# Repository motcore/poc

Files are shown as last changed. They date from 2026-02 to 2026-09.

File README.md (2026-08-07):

# Motcore

**Multi-Axis Actuator Tree — one motor, many axes**






> A novel approach to multi-axis actuation: one motor, multiple independently controlled axes through selective friction engagement.

<!-- TODO: demo video — once it's recorded and hosted, restore as the first item:
     [🎥 Demo Video](URL) | -->
[📖 Documentation](docs/) | [🧬 Design Evolution](docs/design-evolution.md) | [💬 Discussions](../../discussions) | [🐛 Issues](../../issues)

---

## 🚧 Project Status

**Current version: v0.1 - Proof of Concept**

This is an **early-stage open hardware project** developed in spare time. The current prototype uses LEGO Technic components to validate the core mechanical principle. It works, it demonstrates the concept, but it's not production-ready.

**What exists today:**
- ✅ Functional proof of concept
- ✅ Arduino-based control system
- ✅ Validated friction-based power transmission
- ✅ Independent control of 4 output axes

**What's being developed:**
- 🔄 v5 vertical cone clutch — geometry settled, CAD pending
- 🔄 3D-printable components (FreeCAD parametric models)
- 🔄 Comprehensive documentation
- 🔄 BOM with standard components

The mechanism has been through **five generations**. Four are superseded and
should not be re-proposed — see [Design Evolution](docs/design-evolution.md) for
what each one was and what killed it.

**Timeline:** When it's ready. No pressure, no deadlines. Life happens. 🙂

---

## 💡 The Problem

Traditional multi-axis systems face a fundamental trade-off:

| Approach | Cost | Complexity | Independent Control |
|---|---|---|---|
| **One motor per axis** | High | Low | ✅ Yes |
| **Mechanical coupling** | Medium | High | ❌ No (coupled motion) |
| **Motcore** | **Low** | **Medium** | **✅ Yes** |

**Motcore fills the gap:** affordable multi-axis control without sacrificing independence.

---

## 🎯 The Motcore Solution

### Core Innovation

A single continuously rotating motor drives multiple output axes through
**vertical conical friction clutches**. Each axis has its own clutch module on a
carriage that translates vertically; engaging a clutch connects that axis to the
motor cone. Each output feeds the **next hub of the tree**, so every level is a
reduction — torque is regenerated at each stage, and speed is the resource there
is plenty of.

```
        side view (one axis, Y-Z cross-section)

           motor axis (Z)
                │
                │        ┌───┐  ← output cone on carriage
                │       ╱     ╲       (translates vertically ↕)
                │      │  ○ ○  │ ── output shaft (fixed)
              ╱ │ ╲     ╲     ╱       + internal corona
             ╱  │  ╲     └───┘
            ╱ ○ │ ○ ╲   ← O-rings interleaved, flank to flank
           ╱────┴────╲
             motor cone
```

**Key principle:** selective friction engagement as a power transmission method —
with **free rotation obtained geometrically**, not by loosening a clutch.

### Features

✅ **Single inexpensive motor** — 28BYJ-48 stepper (€3)  
✅ **Independent axis control** — 4+ axes, each controllable separately  
✅ **Real free rotation** — a disengaged axis carries *nothing*, so an arm can fall under its own weight  
✅ **Reduction at every level** — 1.4× torque per stage, not 1:1  
✅ **Per-axis torque limiter** — slip threshold set in software by carriage position  
✅ **Scalable** — add more axes without changing the central motor  
✅ **Low cost** — complete system ~€50 in components  
✅ **Educational platform** — demonstrates mechanical principles elegantly  

---

## 🧠 Design Philosophy

Motcore is inspired by principles of elegant mechanical design:

**Passive Dynamics** (McGeer)  
Like passive walkers that minimize active control, Motcore leverages fundamental physics - friction as a natural power transmission medium.

**Underactuation** (MIT Underactuated Robotics)  
One motor powers multiple independent degrees of freedom through selective engagement. Fewer actuators, smarter design.

**Mechanical Intelligence** (Jansen's Strandbeests)  
The mechanism's geometry and material properties do the "thinking", reducing software complexity.

**Let the parts you already have do the work**  
The engagement stroke needs compliance to preload the friction surfaces. Rather
than add a spring, a slot or a flexure, v5 absorbs that travel in the **root
clearance of the gear it already needed**. No extra part, nothing to tune.

### Why This Matters

Traditional multi-axis systems fight complexity with more complexity (more motors, more controllers, more synchronization). Motcore embraces the opposite: **simplicity through smart exploitation of physical phenomena**.

This isn't just about cost - it's about design elegance.

---

## 🔧 Current Prototype: Arduino Cube

<!-- TODO: photo of the v0.1 LEGO prototype — save as docs/images/prototype-v01.jpg and restore:
     ![Motcore v0.1 Prototype](docs/images/prototype-v01.jpg) -->
*v0.1 proof of concept using LEGO Technic components*

### Technical Specifications

| Component | Specification |
|---|---|
| **Central Motor** | 28BYJ-48 stepper (5V, ~3.5Ω coil resistance) |
| **Motor Driver** | ULN2003 Darlington array |
| **Output Axes** | 4 perpendicular axes (5mm diameter) |
| **Engagement** | 4x SG90 servo motors with friction wheels |
| **Controller** | Arduino Uno (master) |
| **Driver Board** | Arduino Uno (receiver) |
| **Interface** | MCUFRIEND 2.4" TFT touchscreen (240x320) |
| **Communication** | Serial (9600 baud) |
| **Power** | 5V USB |

### How It Works (v0.1 prototype)

1. **Central motor rotates continuously** at constant speed
2. **Servos position friction wheels** to engage/disengage with output axes
3. **Output axes move laterally** to contact different sides of the central shaft
4. **Direction control** through selective engagement (clockwise/counterclockwise)
5. **Independent operation** - each axis controlled separately via touchscreen

*This describes the LEGO proof of concept, which validated the core principle.
The engagement mechanism has been redesigned four times since — see
[Design Evolution](docs/design-evolution.md).*

---

## 🎓 Applications

### Immediate Use Cases
- **Educational robotics** - teach mechanical power transmission
- **Low-cost automation** - simple pick-and-place systems
- **Rapid prototyping** - test multi-DOF concepts quickly
- **Art installations** - kinetic sculptures with multiple motions
- **Research platform** - explore friction-based actuation

### Future Potential
- Multi-axis CNC plotters
- Compliant grippers with variable stiffness
- Bio-inspired locomotion (quadruped with 1 motor?)
- Haptic feedback devices
- Prosthetic control systems

---

## 📦 Bill of Materials (v0.1)

| Component | Quantity | Unit Cost | Total |
|---|---|---|---|
| 28BYJ-48 Stepper Motor + ULN2003 | 1 | €3 | €3 |
| SG90 Micro Servo | 4 | €2 | €8 |
| Arduino Uno R3 | 2 | €10 | €20 |
| MCUFRIEND TFT Touchscreen 2.4" | 1 | €15 | €15 |
| Jumper wires, breadboard | - | €5 | €5 |
| **TOTAL** | | | **€51** |

*LEGO components not included - used for proof of concept only*

**v0.2 BOM (in development)** will replace LEGO with 3D printed + standard mechanical components.

---

## 🚀 Getting Started

### Prerequisites

**Software:**
- [PlatformIO](https://platformio.org/) (recommended) or [Arduino IDE](https://www.arduino.cc/en/software)
- [FreeCAD](https://www.freecad.org/) (for 3D models, optional)

**Hardware:**
- Components from BOM above
- 3D printer (optional - for v0.2 components)

### Installation

```bash
# Clone the repository
git clone https://github.com/Motcore/poc.git
cd poc

# Open in PlatformIO
# OR open src/controller/ and src/driver/ in Arduino IDE
```

### Quick Start

1. **Upload firmware**
   - Upload `src/controller/` to master Arduino
   - Upload `src/driver/` to receiver Arduino

2. **Wire according to schematic**
   - See [docs/wiring.md](docs/wiring.md) for pinout

3. **Assemble mechanical components**
   - See [docs/assembly.md](docs/assembly.md) for step-by-step

4. **Power on and test**
   - Use touchscreen interface to control axes

---

## 📚 Documentation

| Document | Description |
|---|---|
| [Design Evolution](docs/design-evolution.md) | The five generations, what killed each one, what survived |
| [Clutch Geometry](docs/clutch-geometry.md) | v5 derivation — cone angles, ratios, ring interleaving, constraints |
| [Assembly Guide](docs/assembly.md) | Step-by-step build instructions |
| [Wiring Diagram](docs/wiring.md) | Electrical connections and pinout |
| [Firmware Guide](docs/firmware.md) | Code architecture and customization |
| [3D Models](docs/3d-models.md) | FreeCAD parametric design (v0.2) |
| [Build Log](docs/build-log.md) | Prototype journal — BOM, prints, calibrations, tests |
| [Troubleshooting](docs/troubleshooting.md) | Common issues and solutions |

### 🛠️ Design Tools

| Tool | Description |
|---|---|
| **[v5 Vertical Cone Clutch Visualiser](https://htmlpreview.github.io/?https://github.com/motcore/poc/blob/main/cad/clutch_geometry_v5.html)** | **Active.** Interactive Y-Z cross-section. Live sliders for α, m, Zp/Zc, L, s₀, d, n, g, δ; the four carriage stops; an inset showing the pinion inside the corona; and live constraint checking. |
| [FreeCAD Macro — Calibration coupon](cad/calibration.py) | FDM tolerance calibration coupon. Print before anything else. |

<details>
<summary>Superseded design tools (kept for the record — do not build from these)</summary>

| Tool | Generation |
|---|---|
| [Bevel Clutch Geometry Visualizer](https://htmlpreview.github.io/?https://github.com/motcore/poc/blob/main/cad/clutch_geometry.html) | v2 — bevel cone |
| [O-ring Clutch Geometry Visualizer](https://htmlpreview.github.io/?https://github.com/motcore/poc/blob/main/cad/clutch_geometry_v3.html) | v3/v4 — tilting flat disc |
| [FreeCAD Macro — Plates](cad/motcore_plates.py) | v2 — plates, motor cone, clutch cone |
| [FreeCAD Macro — Animation](cad/motcore_animate.py) | v2 — tilt animation around the UJ pivot |
| [FreeCAD Macro — v1 O-ring clutch](cad/motcore_v1.py) | v3 — printed compliant neck |
| [FreeCAD Macro — Compliant lever](cad/motcore_compliant_lever.py) | v4 — metal UJ + engagement blade + over-centre latch |

</details>

---

## 🔩 v5 Design Notes — Vertical Cone Clutch

Full derivation in [docs/clutch-geometry.md](docs/clutch-geometry.md); the
interactive visualiser is `cad/clutch_geometry_v5.html`.

### Mechanism

The motor cone sits on the central vertical shaft. The output cone rides a
**carriage that translates vertically** on two 3 mm guide rods — no tilt, no
pivot, no universal joint, one degree of freedom. Three ideas carry it:

**1. Rubber meets rubber.** The motor cone carries `n` O-rings on its
generatrix, the output cone `n − 1` offset by half a pitch, so the two sets
**interdigitate** and touch flank to flank. That gives μ ≈ 1.2–1.5 instead of
the 0.6–0.9 of rubber on plastic, and the rings never touch the plastic at all.
Preload is **radial between flanks**, so it is decoupled from apex displacement.

**2. Free rotation is geometric.** A pinion rigid to the output cone lives
permanently **inside** an internal corona fixed to the output shaft — captive by
construction, it can never fall out. Free = pinion **concentric** with the
corona, centre distance 0, so the output shaft carries *nothing*. No friction
threshold, which matters because lifting an arm and letting it fall demand the
same torque; no threshold can separate them.

**3. It reduces.** Friction 1.428 × gear 0.500 = **0.714**, i.e. 1.4× torque per
stage. The output feeds the next hub of the tree, so torque has to be
regenerated at every level.

### Four carriage positions, descending

| # | Position | State |
|---|---|---|
| 1 | **Free** | pinion concentric, rings separated, output shaft drives nothing |
| 2 | **Mesh** | centre distance `e` reached, rings **still separated**, relative velocity zero → teeth engage without shock |
| 3 | **Contact** | rubber flanks touch, normal force zero |
| 4 | **Preload** | flanks compressed, torque transmitted |

Preload travel is absorbed by the gear's own **root clearance** (0.25 · m) — no
slot, no floating ring, no compliant blade.

### Key Design Parameters

| Parameter | Value | Notes |
|---|---|---|
| Motor cone half-angle α | 55° | from the vertical axis; output cone = 90 − α |
| Gear module m | 1.0 | |
| Pinion / corona teeth Zp / Zc | 14 / 28 | internal mesh, reducing |
| Contact line length L | 18 mm | along the generatrix |
| Apex → contact line s₀ | 10 mm | |
| O-ring wire d | 2.5 mm | rubber on rubber |
| Rings on motor cone n | 5 | output cone carries n − 1 |
| Margin g | 0.20 mm | full mesh → rubber contact |
| Preload δ | 0.25 mm | past contact |

### Derived

| Metric | Value |
|---|---|
| Friction ratio | 1.428 |
| Gear ratio | 0.500 |
| **Total ω_out / ω_motor** | **0.714 → 1.4× torque** |
| Centre distance `e` | 7.00 mm |
| Free float / mesh travel | 5.00 / 2.00 mm |
| **Total carriage stroke** | **7.45 mm** |
| Ring pitch q | 2.25 mm (< d ✓) |
| Apex separation | 1.33 mm |
| Micro-slip | ≈ 7.4 % |

### Open questions — not settled

- [ ] **Ring density vs micro-slip.** More rings interdigitate better but push
      the cones apart. n=5 → 7.4 %, n=7 → 13.6 %, n=3 → flanks never touch.
      Narrow window; needs a sweep over `L` and `d`.
- [ ] **`g + δ` exceeds root clearance at m = 1** (0.45 vs 0.25 mm). Unresolved.
- [ ] **Re-meshing while the output shaft still turns** clashes teeth. Firmware
      must gate engagement on an AS5600 velocity check.
- [ ] **Ring manufacture.** Catalogue O-rings fix the diameters; the pitches then
      have to land on the generatrix.
- [ ] **CAD.** Geometry is settled in the visualiser; the FreeCAD macro is not
      written yet.

### Position feedback is structural

Friction slip accumulates non-repeatably in series along a tree, so position is
only known by **measuring** it. An **AS5600** on every output shaft is part of
the mechanism, not an optional extra. Its I2C address is fixed at 0x36, so
multiple encoders need multiplexing (analog output, PWM, or a TCA9548A).

---

## 🗺️ Roadmap

### v0.2 - 3D Printed Prototype (In Progress)
- [ ] Parametric FreeCAD model of the v5 vertical cone clutch
- [ ] Carriage + 3 mm guide rods, single-DOF actuation
- [ ] Resolve `g + δ` vs root clearance
- [ ] Sweep `L` and `d` for the ring density / micro-slip window
- [ ] Source O-rings and land the ring pitches on the generatrix
- [ ] Complete assembly documentation

### v0.3 - Refinement
- [ ] AS5600 on every output shaft, with multiplexing
- [ ] Velocity-gated engagement (no re-mesh while the shaft turns)
- [ ] Torque measurement and control
- [ ] Multiple friction material testing
- [ ] Calibration procedures

### v1.0 - Production Ready
- [ ] Optimized BOM with sourcing links
- [ ] PCB design for integrated controller
- [ ] Comprehensive documentation
- [ ] Video tutorials
- [ ] Academic paper publication

### v2.0 - Advanced Features
- [ ] Scalable to 6+ axes
- [ ] Encoder feedback for precise positioning
- [ ] ROS integration
- [ ] Alternative engagement mechanisms

**Note:** These are aspirational goals, not commitments. Progress happens when contributors have time.

---

## 🤝 Contributing

**Contributions are welcome!** This project is developed by volunteers in their spare time.

### How to Contribute

We appreciate help in any form:

**🔧 Engineering & Design**
- FreeCAD models of components
- FEM analysis of compliant mechanisms
- Alternative engagement system designs
- Friction material testing

**📝 Documentation**
- Improve assembly instructions
- Create diagrams and illustrations
- Write troubleshooting guides
- Translate documentation

**💻 Software**
- Improve firmware efficiency
- Add new control modes
- Create calibration routines
- Develop GUI improvements

**🧪 Testing & Feedback**
- Build the prototype and report results
- Test different materials
- Measure performance metrics
- Share your modifications

### Contribution Guidelines

1. **No pressure, no deadlines** - contribute at your own pace
2. **Open from day one** - all work is immediately open source
3. **Credit always given** - contributors are acknowledged
4. **Discuss first** - open an issue before major work
5. **Be kind** - respectful collaboration always

See [CONTRIBUTING.md](CONTRIBUTING.md) for detailed guidelines.

---

## 📄 Licenses

This project uses multiple licenses for different components:

### Hardware & Mechanical Design
**CERN Open Hardware Licence Version 2 - Permissive (CERN-OHL-P-2.0)**

You are free to use, modify, and distribute the hardware designs, even commercially, as long as you provide attribution and include the license text.

[LICENSE-HARDWARE.md](LICENSE-HARDWARE.md)

### Software & Firmware
**MIT License**

You are free to use, modify, and distribute the software, even commercially, with minimal restrictions.

[LICENSE-SOFTWARE.md](LICENSE-SOFTWARE.md)

### Documentation
**Creative Commons Attribution-ShareAlike 4.0 International (CC BY-SA 4.0)**

You are free to share and adapt the documentation, even commercially, as long as you provide attribution and distribute your contributions under the same license.

[LICENSE-DOCS.md](LICENSE-DOCS.md)

---

## 🙏 Acknowledgments

**Original concept and design:** Javier Asensio Montiel (2025)

**Inspired by:**
- Steve McGeer's work on passive dynamic walking
- Theo Jansen's Strandbeest kinetic sculptures
- Research on compliant mechanisms
- Underactuated robotics principles
- Piezoelectric actuator design philosophy

**Special thanks to:**
<!-- TODO: list contributors here as they join -->
- Contributors will be listed here as they join

---

## 📞 Contact & Community

- **GitHub Issues:** [Bug reports and feature requests](../../issues)
- **GitHub Discussions:** [Questions, ideas, and general chat](../../discussions)

<!-- TODO: add contact channels once they exist —
     - **Email:** <address>
     - **Hackaday.io:** <project URL>
     - **LinkedIn:** <profile URL>
-->

---

## 💬 FAQ

### Is this production-ready?
No. This is an early prototype demonstrating the concept. v0.1 uses LEGO components. v0.2 is being designed with proper mechanical parts.

### Can I build this myself?
Yes! The v0.1 BOM and basic instructions are available. v0.2 documentation is being developed.

### Will this be commercialized?
This is an open hardware project. Anyone can manufacture and sell kits, as long as they comply with the CERN-OHL-P license. The design will always remain open.

### How precise is the positioning?
Current prototype: low precision (proof of concept). v0.2+ will explore encoder feedback for improved accuracy.

### Can it handle heavy loads?
The current design is optimized for light loads (educational/prototyping). Load capacity depends on friction wheel material and contact pressure.

### Why friction drive instead of gears?
Friction allows variable torque transmission, compliance, and simple
engagement/disengagement — and it doubles as a per-axis torque limiter. The
trade-off is efficiency and precision: slip accumulates non-repeatably, which is
why v5 puts an encoder on every output shaft. v5 actually uses **both** — a
friction stage for engagement and torque limiting, and a gear stage for
reduction and for free rotation.

### How can a friction clutch give true free rotation?
It can't, and that's what killed four generations. Lifting an arm and letting it
fall demand the same torque at the shaft, so no slip threshold separates them.
v5 sidesteps it: free rotation comes from the **gear** stage, where the pinion
sits concentric inside the corona at centre distance 0 and the output shaft
carries nothing at all.

### Why does the design reduce instead of running 1:1?
Because each output feeds the next hub of a tree. Torque is consumed going down
and must be regenerated at every level; speed is the resource there is plenty of.

---

## ⭐ Support the Project

If Motcore is useful or interesting to you:

- ⭐ **Star this repository** - helps others discover the project
- 🐛 **Report bugs** - help improve reliability
- 💡 **Suggest ideas** - shape the project's direction  
- 🔧 **Contribute code/designs** - make it better
- 📖 **Improve documentation** - help others understand
- 📢 **Share the project** - spread the word
- 💰 **Sponsor development** (future: Open Collective or similar)

---

## 📊 Project Stats







---

**Motcore** - Making multi-axis actuation accessible through elegant design  
© 2025 Javier Asensio Montiel | Open Source Hardware | CERN-OHL-P-2.0

---

*"Perfection is achieved not when there is nothing more to add, but when there is nothing left to take away."*  
*- Antoine de Saint-Exupéry*

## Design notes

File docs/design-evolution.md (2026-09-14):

# Motcore — Design Evolution

Five generations of the same question: **how does one motor drive many axes
independently, cheaply, and with real free rotation?**

Each generation was killed by a specific, identifiable failure — not by taste.
This document records what each one was, what broke it, and what survived into
the next. Nothing here is a proposal; the only live design is **v5**.

> This file is the source of truth. It is also published, with diagrams, at
> **[motcore.github.io/evolution](https://motcore.github.io/evolution)**
> (`src/pages/evolution.astro` in the `motcore.github.io` repo). Update this
> file first, then mirror the change there.

| Gen | Dates | Mechanism | Status |
|-----|---|---|---|
| **v1** | Mar–May 2026 | LEGO + lateral friction wheels | superseded |
| **v2** | May 2026 | Bevel cone friction drive, common apex | superseded |
| **v3** | Jun 2026 | Flat motor disc + O-ring wheel, printed compliant neck | superseded |
| **v4** | Jun–Jul 2026 | Metal UJ + engagement blade, over-centre latch | superseded |
| **v5** | Aug 2026 | Vertical conical clutch, interleaved O-rings, captive pinion | **active** |

The numbering follows **design generations**, not files. There is no
`clutch_geometry_v2.html` or `_v4.html` — v2 is `clutch_geometry.html`
("Bevel Clutch Geometry"), and v4 reused v3's visualiser because its geometry
was unchanged in the Y-Z cross-section.

---

## v1 — LEGO proof of concept

*Lateral friction wheels, ~Mar–May 2026*

One 28BYJ-48 stepper turning continuously; four SG90 servos pushing friction
wheels against the sides of a central shaft. Output direction depended on which
side of the shaft the wheel touched. Frame in LEGO Technic.

**What it proved:** selective friction engagement works as a transmission
method, and four axes can be driven independently from one motor. This is the
result the whole project rests on.

**Why it was superseded:** LEGO tolerances, no real parameter control, and no
way to reason about contact geometry. It was a demonstrator, never a design.

**Survived into later generations:** the two-Arduino architecture
(controller + driver), the touchscreen UI, and the basic BOM.

---

## v2 — Bevel cone, common apex

*`cad/motcore_plates.py`, `cad/motcore_animate.py`,
`cad/clutch_geometry.html`, May 2026*

A truncated cone on each output shaft, tangent along a **common generator line**
to a cone on the motor shaft. The output shaft tilted around a UJ pivot near the
wall to bring the cones into contact. Both cones shared an apex, so the
`α_clutch + α_motor = 90° − A` bevel condition held automatically for any choice
of A, B, C, D.

Defaults: A = 8°, B = 35 mm, C = D = 9 mm, L ≈ 42.4 mm, α ≈ 49° for both cones.

**What it fixed:** differential slip. Line contact along a common generatrix
means every point on the contact line has matched surface speed — a flat wheel
on a flat disc does not.

**Why it was superseded:** the full derivation lives in
[archive/clutch-geometry-bevel.md](archive/clutch-geometry-bevel.md). In short,
holding the common apex through a tilt made every dimension depend on the
engagement angle, and the plastic-on-plastic (later plastic-on-rubber) contact
had too little friction to be useful at achievable normal forces.

**Survived:** the common-apex idea itself, which is still the core of v5 — only
now the apexes are held by translating a carriage instead of tilting a shaft.

---

## v3 — Flat disc + O-ring wheel, compliant flexure

*`cad/motcore_v1.py`, `cad/clutch_geometry_v3.html`, Jun 2026*

The motor cone became a **flat horizontal disc** with two usable faces. Each
output shaft carried a wheel with a silicone O-ring in a toroidal groove, and
tilted ±A to press that O-ring against the top face (one direction) or the
bottom face (the other). The tilt came from flexure blades printed in one piece
with the wall, plus a compliant neck in the printed shaft.

Defaults: A = 3°, B = 35 mm, R = 20 mm, O-ring wire 2.5 mm, blade 1.5 × 6.0 mm,
neck Ø2.5 × 13 mm. Contact force ≈ 4.85 N, output torque ≈ 58 N·mm,
speed ratio ≈ 1.39× the motor.

**What it fixed:** friction. Rubber on plastic (μ ≈ 0.6–0.9) beats cone-on-cone
plastic by a wide margin, and one disc with two faces gave both directions from
a single motor without reversing it.

**Why it was superseded:** the printed compliant neck was the weak link — it had
to be soft enough to tilt and stiff enough to carry output torque, and those two
requirements pulled in opposite directions. Output torque was low
(58 N·mm), and the design multiplied speed (1.39×) when what a tree of actuators
needs is torque.

**Survived:** O-rings as the friction element, and the torque-limiter framing —
a slipping clutch protects the drivetrain, and slip threshold is settable in
software.

---

## v4 — Metal UJ + engagement blade, over-centre latch

*`cad/motcore_compliant_lever.py`, Jun–Jul 2026*

The most developed of the superseded branches, and the one that got printed.
The printed neck was replaced by a **purchased metal universal joint**
(Ø11 × 23 mm, 5 mm bore) straddling the wall, with metal Ø5 mm output shafts in
two segments. All compliance moved into a printed **engagement blade**: a thin
spring section driven by a pin on a short (4 mm) servo arm riding in a slot.

Its best trick was the **over-centre latch** — the servo arm swept just past its
90° dead point onto a hard stop, so the spring held the clutch engaged with the
**servo unpowered**. Current only flowed during transitions. Blade geometry was
sized to keep sustained latch stress ≈ 14 MPa so PETG creep stayed negligible.

Defaults: A = 1.5°, B = 35 mm, R = 20 mm, contact radius R_out = 15 mm,
ratio ≈ 0.75 (ω_out ≈ 1.34 × ω_motor), T_out ≈ 250 N·mm at the latch — roughly
2× the servo's own continuous torque.

Weeks of FDM work went into this branch: bearing seats, M3 clearance passes, a
dovetail O-ring groove to stop the ring slipping, a two-part printable motor
disc, a corner-post cage frame.

**Why it was superseded — this is the important one.** A friction clutch with a
fixed threshold cannot give **free rotation**. To let an arm fall under its own
weight, the clutch must transmit nothing; to lift that same arm, it must
transmit torque. Both demand the same magnitude of torque at the shaft, so
**no threshold separates them**. Loosening the clutch enough to let the arm fall
also loses the ability to lift it. Every fix within the tilting-clutch family
runs into this wall.

The second problem: at ratio 0.75 the design still multiplied speed. Feeding one
axis into the next hub of a tree means torque has to be *regenerated* at every
level, and v4 spent it instead.

---

## v5 — Vertical cone, interleaved rings, captive pinion

*`cad/clutch_geometry_v5.html`, Aug 2026 — **active***

Full description in [clutch-geometry.md](clutch-geometry.md) and the project's
`CLAUDE.md`. The three changes that answer v4's failures:

**1. Free rotation is geometric, not frictional.** A pinion rigid to the output
cone lives permanently *inside* an internal corona fixed to the output shaft.
Free = pinion **concentric** with the corona, centre distance 0 — the output
shaft carries nothing at all. No threshold, no residual drag, no compromise
between lifting and falling. The pinion is captive by construction and cannot
fall out.

**2. Rubber meets rubber.** Both cones carry O-rings — `n` on the motor cone,
`n − 1` on the output cone, offset half a pitch so the two sets
**interdigitate** and touch flank to flank. μ ≈ 1.2–1.5 instead of 0.6–0.9, and
the rings never touch the plastic. Preload is **radial between flanks**, which
decouples it from apex displacement: pushing harder no longer requires the cones
to move axially into each other.

**3. It reduces.** Friction ratio 1.428 × gear ratio 0.500 = **0.714**, i.e.
**1.4× torque**. Speed is the surplus resource in a tree; torque is not.

**4. Two motor cones, apex to apex — so each axis is bidirectional.** This is
what v3/v4's "one disc, two usable faces" becomes in cone form. The two cones
share the central shaft and turn the same way, but their flanks face opposite
sides of the output axis: drive the carriage down and the output shaft turns
one way, up and it turns the other. One motor, one axis, both directions,
without ever reversing the motor.

Actuation collapses to a single degree of freedom — the vertical position of a
carriage on two 3 mm guide rods. **Free is the middle**, and the same four-stop
ladder runs both ways from it:

| # | Position | \|z\| from mid-plane | State |
|---|---|---|---|
| 1 | Free | 0 | pinion concentric, rings separated, shaft drives nothing |
| 2 | Mesh | `e` | centre distance reached, rings still separated, relative velocity zero → teeth engage without shock |
| 3 | Contact | `e + g` | rubber flanks touch, normal force zero |
| 4 | Preload | `e + g + δ` | flanks compressed, torque transmitted |

Half stroke 7.65 mm, full travel 15.30 mm at defaults. The motor cone apexes
sit at ±(e + g) — derived, not chosen, since that is what keeps the apexes
common at contact. Preload travel is absorbed by the gear's own root clearance
— no slot, no floating ring, no compliant blade.

Four axes, one per cube wall; the cube comes out ~130 mm a side.

**Still open, not settled:** ring density versus micro-slip (≈ 7.4 % at n = 5,
13.6 % at n = 7, flanks never touch at n = 3); tooth clash if the carriage
re-meshes while the output shaft is still turning; and how the rings are
actually manufactured. See the open questions in `CLAUDE.md`.

**Closed since:** `g + δ` exceeding the root clearance. It was a floor on the
module all along (`m ≥ 4·(g + δ)`); the module is now 1.8 with 8/16 teeth,
which satisfies it exactly — at zero margin, as is `Zc − Zp = 8`.

---

## What carried through all five

- **One motor, many axes, selectively engaged.** Never in question since v1.
- **Common apex / matched surface speed.** Introduced in v2, still the core of v5.
- **O-rings as the friction element.** Introduced in v3.
- **Friction as a per-axis, software-settable torque limiter.** Introduced in v3.
- **Both directions from one non-reversing motor**, by engaging one of two
  opposed friction surfaces. v1 chose a side of the shaft, v3/v4 the top or
  bottom face of the disc, v5 the lower or upper motor cone.
- **Two-Arduino split**, controller and driver. Unchanged since v1.

## Dead ends — do not re-propose

- **Tilting a shaft (universal joint, printed neck, or flexure) to engage.**
  v2, v3 and v4 all did this. Superseded by carriage translation.
- **Laboratory conical rubber stoppers** as friction elements. Two reasons, and
  the second one rules out any bulk-rubber element, not just stoppers. First,
  the taper: a standard stopper is 7-10° of half-angle (a #11 is 56/47 mm over
  25 mm high, i.e. 10.2°) where the design needs 33° and 55° — and `α+β` *is*
  the angle between the axes at contact, so a pair of stoppers would put the
  output shaft nearly parallel to the motor shaft instead of perpendicular to
  it. Two equal cones would also give `ratio_fric = 1`, against invariant 1.
  Second, and deeper: a solid rubber cone has to carry the output torque
  through its own body in torsion. For R ≈ 12 mm, L ≈ 25 mm and G ≈ 1 MPa,
  `θ = T·L/(G·J)` is **~105° of wind-up at 2.4 Nm** (still 22° at 0.5 Nm),
  against ~6° for a 2 mm layer bonded to a rigid cone, whose shear path is 2 mm
  instead of 25. That is the real reason the rubber must be **thin and backed
  by something stiff**, and it is the same reason the drive load goes straight
  through the layer into the cone rather than along it. The instinct behind the
  idea — one seamless bulk rubber part, no wrapping and no seam — survives as
  **casting** the layer onto the cone.
  *(Reason recorded 2026-09-14; the original entry carried none, which is why
  it came back up.)*
- **Fixed-threshold friction clutches to obtain free rotation.** Lifting and
  falling demand the same torque, so no threshold separates them.
- **Any 1:1 or speed-multiplying stage.** The tree needs reduction at every level.

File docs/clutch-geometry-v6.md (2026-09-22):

# Clutch geometry — v6 "Apex Pivot"

Status: **active design**, settled 2026-09-12, repacked 2026-09-15, drive and
actuation rebuilt 2026-09-17 (branch `v7-cardan-zigzag`). Supersedes v5
(vertical carriage). The macro is `cad/motcore_v6_apex_pivot.py`; it builds the
assembly and self-checks it (22 numeric checks, plus the rubber template's area), and every number quoted below
that says "measured" comes from its own output.

What changed on 2026-09-17, in one paragraph: the gear stage (pinion, idlers,
corona) and the Oldham that briefly replaced it are gone. The drive out of the
cone is a **folded double cardan living inside the hollow cone**, 1:1. The cone
runs on one thin-section bearing on its neck. The four-bar moved to a 45° ray
with shorter links. The actuation is a **servo under the ceiling → torsion
spring → horn → 2.1:1 lever → link → ear on the carriage**, and all four axes are
identical rotated copies. Cube **106.4 mm**.

---

## 1. The one-line change

In v5 the output cone **translated vertically** to engage. In v6 it **pivots
about the common apex**. Everything else follows from that.

The apex stops being a point the geometry passes through and becomes the hinge
the whole carriage swings on. It never moves, in any position.

---

## 2. What that buys

- **Preload acts exactly along the contact normal.** Rotating about the apex
  moves every point of the cone surface perpendicular to the shared generatrix,
  which is the contact normal. 100% of the push does useful work. In v5 the
  vertical push only delivered 87%, and the other 13% went sideways into the
  guide rods.
- **The apexes never separate.** In v5 the preload overtravel (δ) pushed the
  output cone 0.25 mm past the position where the apexes coincide, adding ~1.4%
  slip. Here the apex is the pivot, so preload adds zero apex error.
- **The motor cones can share one apex.** v5 had to hold them 14.8 mm apart
  (at ±(e+g)); in v6 their rubber surfaces converge on a single point, so the
  hourglass waist closes and the cube gets shorter.
- **The carriage is a lever.** The push arrives further from the apex than the
  rubber does, so a newton on the ear becomes **×1.46** of total normal force
  (ear at y = 42.9 mm, squeeze centroid s̄ = 29.4 mm, both measured). Read that
  as force, not as torque: see §8 — where the contact sits cancels out of the
  output torque exactly.
- **The box.** 145 mm (first v6) → 119 (hollow cone, gears behind the push
  point) → 120.8 (Oldham) → **106.4 mm** now, set by the servo case under the
  ceiling.

---

## 3. Cone geometry and the apex compensation

Three cones share one apex at the origin, on the motor axis:

- two motor cones, half-angle **α = 55°** from the vertical (Z) axis, flaring
  away from the waist;
- one output cone per wall, half-angle **β = 33°** from its own (Y) axis.

Contact happens when the angle between the axes equals α + β. At rest the axes
are perpendicular, so the **free gap angle** is

```
φc = 90° − α − β = 2°
```

Rotating the carriage by −φc closes the gap onto the lower motor cone, +φc onto
the upper one. Free is the middle, as in v5.

### The compensation that kills micro-slip

The rubber is a **continuous layer of thickness t = 2 mm** on each cone (see §4),
so the surface that actually touches sits t proud of the plastic. Offsetting a
cone's surface outward by t moves its apex backwards along its own axis by

```
apex offset = t / sin(half-angle)
```

So the **plastic** apexes are pulled back deliberately, and the **rubber**
surfaces are what converge on the origin:

| Cone | Offset along its own axis |
|---|---|
| each motor cone | 2 / sin 55° = **2.44 mm** |
| output cone | 2 / sin 33° = **3.67 mm** |

With that, the contact line passes through the point where the two axes cross,
which is the condition for matched surface speeds. **Micro-slip ≈ 0**, against
7.4% in v5.

This is the thing interleaved O-rings could not do: their offset came out of the
interdigitation geometry and was not freely correctable.

The band runs s = 10.0…33.4 mm from the apex on the rubber surface (L = 23.4 mm,
derived: it fills the cone and stops 2 mm short of the rim for a bonding lip).

---

## 4. Continuous rubber layer (replaces the O-rings)

v5 used `n` O-rings on the motor cone and `n−1` on the output cone, interleaved
half a pitch so the flanks met rubber-on-rubber. v6 drops them for a **uniform
rubber layer** on both cones.

Why:

- **Contact area.** Two crossed rings touch at a point; two coated cones touch
  along the whole generatrix. Far more grip for the same squeeze.
- **Zero micro-slip**, via the compensation above.
- **No pitch matching** between the two ring sets, and no `q < d` constraint.

How to make it: a cone is a developable surface, so it unrolls into a flat
annular sector (295° for the motor cone, 196° for the output). The macro writes a
1:1 cutting template, `cad/motcore_v6_flat_pattern.svg`, with a spiral seam that
crosses the contact line at a single sweeping point. **Not yet tested** — see
open questions.

Rubber on rubber stays the rule: the plastic surfaces never touch.

### Park in free, always

Idler-wheel turntables — Garrard, Lenco — drove exactly like this, a thin rubber
tyre on a rigid hub transmitting by friction. Their classic failure was a **flat
spot**: left switched off with the idler still pressed against the motor spindle,
the rubber took a permanent set at that one point, and afterwards it thumped once
per revolution. Good decks lifted the idler when you switched off.

The same applies here, and the numbers are not comfortable: the working squeeze
is ~0.08 mm on a 2 mm layer, and butyl — the obvious prototype material, since a
bicycle inner tube is one — is among the worst rubbers for compression set. Thirty
percent of that squeeze taken as permanent set is 0.024 mm, a third of the
preload, at **one azimuth of each cone**. That is the turntable thump again.

v6 looks immune because free is the middle of the travel, with the rubber clear
on both sides — but the carriage does not return there by itself. Gravity acts
**within** the tilt plane on all four axes (each tilt plane contains Z), so it
pulls toward the lower motor cone rather than toward the middle, and with the
servo unpowered what actually holds the carriage is the servo's own gearbox,
which is stiff to back-drive. The carriage stays wherever firmware left it.

So it is a firmware rule, not a property of the mechanism: **command free before
cutting power, and do not rest in preload between movements.** Making it true
even through a crash or a flat battery would need a centring spring on the
carriage itself — the four-bar links are the natural place — and that is design,
not a line of code.

---

## 5. The virtual pivot (four-bar)

The apex sits on the motor shaft, so no physical bearing can go there. The
carriage hangs on a **four-bar linkage whose two link axes converge on the
apex**; the instant centre of the carriage is therefore the apex itself.

Current geometry (Y-Z plane, apex at origin):

| | |
|---|---|
| Link axis angles | ±45° from the Y axis, both through the origin |
| Frame pivots | radius 55 mm, on posts screwed to the wall |
| Carriage pivots (B) | radius 40.5 mm |
| Link length | 14.5 mm |
| Sets | two, one at each side in X, joined by a knuckle **on B** into one part |

Why 45°/55: with the Oldham gone the frame post was what set the cube (54.5).
Sweeping the linkage, ray 45° with the frame pivot at r = 55 brings the post
under the next constraint for 0.61% slip; ray 40° at r = 52 gets the same cube at
0.65%. The carriage pivot cannot come in below r = 40.5 without landing on the
motor cone's rim. The knuckle sits on B because a 14.5 mm link is too short for
the frame post's lug and a mid-span knuckle to share; at B the 45° ray keeps it
1.9 mm off the motor cone (swept check).

**Measured by the macro** (`apex_drift`, on the linkage's own solved pose): at
full preload the point that started at the apex moves **0.187 mm** (0.132 at
contact), **+0.140 along** the shared generatrix (slip) and **−0.124 normal** to
it (preload error, 6% of the rubber thickness). Residual slip **0.60%** of the
contact line, against v5's 7.4%. Not zero: do not quote "≈ 0".

Because the drift is outward along +Y it OPENS the contact: contact really
happens at **2.18°**, not 2.00°, first at the band's outer end, and spreads
inward as the preload grows. The usable preload travel is +0.20° past real
contact.

The **instant centre** itself wanders much further. That is normal four-bar
behaviour and not a fault: what matters is how far the apex *point* travels.

Links must not be at ±35°: that is exactly the shared generatrix direction, i.e.
the cone surfaces. Anything between 33° and 35° is inside the clearance wedge.

A flexure version was considered and **deferred to v7** — PLA creeps under
sustained load, and the project already abandoned a compliant blade in v4.

The carriage itself is now a **ring round the cone's neck** (§6) holding the
bearing, with two arms at x = ±15 whose uprights are flush with the ring (y 33…42) and run to B at 45°.

---

## 6. Drive out of the cone — folded double cardan, 1:1

The cone tilts about the apex and the output shaft does not. At distance y from
the apex their axes are apart by y·sin φ **and** at an angle φ. Whatever couples
them must take both.

```
cone (outer yoke) → ring cross → intermediate tube → solid cross → fork → output shaft
```

- **The cone is the outer yoke.** It is a hollow shell, solid only to y = 18,
  with a Ø20 bore from where its cavity is that wide out through a **neck**. The
  neck carries **one 6805 (25×37×7)** on its outside, held by the carriage ring —
  there is no carriage shaft any more — and the ring cross's X pins through its
  wall, under the bearing, which keeps them in.
- **Ring cross at y = 40, on the cone axis.** Ø10.2 bore / Ø14.6 × 5 mm: the
  output shaft passes through it. Its wall was 1.35 mm, which gave its pins
  nowhere to sit (~30 MPa on the plastic at 1 Nm, 0.5 mm beside each hole); now
  2.2 mm (~18 MPa) and 1.5 mm beside each hole. The neck's bore is Ø21 round it,
  leaving 2.0 mm of neck wall for the X pins — the limit with a 6805.
- **Intermediate: a stepped tube** running back toward the apex, 14.0 mm
  between pin planes: Ø13.5/16.5 at its tail, where it sits in the cone's
  conical cavity and cannot grow, and Ø15.6/19.6 only round the ring. The step
  sits just behind the ring because the tube rocks ~4° inside the cone, which
  moves it sideways by tenths near the ring and by more further back. Windows in
  the head let the ring's X pins out to the neck.
- **Solid cross at y = 26, on the output axis**: a **prism** 4.6 × 4 × 10 mm,
  narrow in X, long in Z. One through pin in X to both arms of a fork keyed to
  the output shaft by a D; two short pins from its long ends to the tube, each
  3.5 mm deep in it. A cube could not take two pins crossing at its centre.
- **Output shaft** in two MR105ZZ: one in a boss on the wall's inner face, one in
  the wall seat. It reaches ~16 mm in from the inner bearing to the fork.

**Why folded, and why it is not constant-velocity.** Both crosses sit in front of
the apex (the motor shaft is behind it). For a double cardan to cancel its own
velocity error the two joints must bend equally, and with the output axis flat
and the ring above it that needs one cross behind the apex. So one joint always
bends φ more than the other. Measured at full preload: **solid cross 6.6°, ring
4.2°**, residual angle error ~ (a₁² − a₂²)/4 = **0.11°** (one Hooke joint at the
tilt would be 0.025°). What the fold buys is a flat intermediate in little
length: its angle is ≈ ring_y·sin φ / (ring_y − cross_y), so moving the solid
cross back toward the apex — into the cone — is what keeps the crosses nearly
straight and the ring bore small. The bore has to swallow the offset between the
axes *at the ring*, which only depends on how far out the ring is.

**Length change.** The ring moves with the cone, the solid cross does not, so the
intermediate's span changes by **0.25 mm** over the stroke. Its ring-end pin
holes are slotted 0.4 mm instead of making the tube telescopic.

Swept clearances (macro, 9 tilts): tightest running gap **0.51 mm**, tube head
against the cone's bore. The model draws one phase of the turn only, so two
checks are analytic: the ring rocking inside the tube's head (0.34 mm) and the
prism rocking inside the tube (0.89 mm).

### Building it

**Not print-in-place.** A printed-in-place joint needs 0.3–0.4 mm of clearance
per pin, which at these radii is ~3° of backlash at the output; supports inside
the closed cone could never be removed; and Ø2 PLA pins at ~70–125 N would
creep.

**Five printed parts and eight steel Ø2 dowel pins** (ISO 8734): cone, tube,
ring, prism, fork. Each pin is **pressed into the cross** (prism or ring) and
**turns free in the part round it**:

| Pin | Pressed into | Turns in | Kept in by |
|---|---|---|---|
| through, prism ↔ fork (X) | — (free in both) | prism and fork arms | its length: sliding to the tube, it is still in both arms |
| prism ↔ tube (Z) ×2 | prism, 3.5 mm | tube tail wall | press fit; the cone's bore 1.75 mm out |
| ring ↔ tube (Z) ×2 | ring, 2.2 mm | slot in the tube head | press fit |
| ring ↔ cone (X) ×2 | ring, 2.2 mm | neck wall | press fit; the 6805 over it |

Holes: this printer runs small holes ~0.5 mm under, so print them at Ø1.5–1.8
and drill — **Ø1.9 for a press, Ø2.1 to turn**. Try both on a coupon first. A
press that comes out loose takes a drop of cyanoacrylate (super glue — not a
Loctite threadlocker, which is anaerobic and does not cure on plastic), on the
pressed side only, before the joint is assembled.

Print the ring solid (100% infill), bore vertical, so its pin holes come out
horizontal and round. PETG takes the oscillation better than PLA.

**Assembly order**, every pin reachable: prism into fork (through pin) → tube
over the prism (its two pins, from outside the tube) → ring into the tube's head
(two pins, through the slots) → the whole thing into the cone through the neck
→ ring's X pins from outside through the neck wall and the tube's windows →
6805 over the neck, trapping them → output shaft in through the wall, the ring's
bore and into the fork's D.

### Printing the carriage

The bearing seat (Ø37, along Y) and the pivot and ear holes (along X) are
perpendicular, so one of them prints lying down. The seat is the one that must
come out round, so the carriage prints **with its wall-side face on the bed**,
seat vertical:

- the 45° jogs out to the pivots B rise off the ring unsupported, and the ear's
  bridge climbs at ~27° from vertical;
- the ring runs on toward the wall past the bearing, to the ear block's own far
  face (y 45.9), so ring and ear stand on the bed together — and that extra
  length **is the bearing's stop**: a solid flange (bore Ø32) from the bearing
  down to the bed, not a lip hanging in the air;
- the bearing goes into the carriage **from the cone side** against that flange;
  then carriage and bearing slide onto the cone's neck together. The neck's
  shoulder holds the inner race on the other side, so the 6805 is located both
  ways;
- the pivot and ear holes print lying down, slightly oval: drill them to size.
  The round bosses round B have a small curved overhang underneath — the first
  thing to look at when the part comes off.

**Plan B for the ring**, if the printed one ovalises: a standard 10 × 14 mm
sintered-bronze bushing (or steel spacer) cut to 5 mm, four radial Ø2 holes
drilled through a printed jig. Its 10.0 bore is 0.2 under the design's, so the
model would need adjusting. For the prism, the steel cross out of a bought mini
cardan, if its size fits the fork and the tube.

---

## 7. Actuation

```
servo → torsion spring → horn → lever 2.1:1 → link → ear on the carriage
```

### Sweep split and the spring

The servo spline turns **±80°** (margin to an MG90's end stops). The first **20°**
bring the rubber into contact; past that the carriage has nowhere to go and the
remaining **60°** wind a **torsion spring without preload** between spline and
horn. Spring torque — not position — sets the squeeze. The horn itself only ever
swings ~25°.

Why the spring sits at the servo and not in a telescopic link: a spring at the
servo only sees force if the servo sees torque, so the chain must have a
near-constant ratio. The old crank ran near dead centre (toggle), where the servo
sees almost no torque — a spring on its shaft would barely wind. Levers and
links far from dead centre keep the ratio steady; the check is that no joint
gets within 40° of dead centre.

Why a lever at all: 1.4 mm of ear travel in 20° of horn needs a 4 mm horn, and
0.2 mm of pin slop on that is 5% of the stroke. Through a 2.1:1 lever the horn is
9.0 mm and servo-side slop reaches the carriage divided.

**The lever rule that makes it "further out is more leverage" false.** Work in =
work out: servo torque × servo angle = carriage moment × tilt. The tilt is fixed
(~2.4°), so the multiplication is fixed by how much servo sweep the stroke uses,
not by where the push lands. Pushing further out gains arm and costs travel in
the same proportion. The push point is chosen for **packaging**.

| Measured / derived | |
|---|---|
| Horn radius (derived from the split and the lever) | 9.04 mm |
| Lever | 8.0 / 3.8 about (y 39.1, z 35.0), on a post from the ceiling |
| Links | link1 7.6 mm, link2 7.5 mm |
| Ear pin | (y 42.9, z 27.5), carriage frame |
| Horn swing | 20.3° to contact, 24.8° at full preload |
| Worst transmission angle | 41.7° |
| Spring (placeholder) | 2.40 N·mm/°, 0.144 Nm after 60° = 80% of MG90 stall |
| At full preload | 34 N on the ear, 1.44 Nm about the apex, 49 N normal |

`spring_ratio` (rubber vs spring stiffness, as servo-side angle past contact) is
**15, invented**; it only sets how far the carriage still creeps past contact
(φ_preload = 2.375°).

### Packaging

- **All four axes are identical, rotated about Z. Nothing is turned over.** Each
  servo sits in its own (+X) corner of the pinwheel. (Alternate axes used to be
  assembled upside down only because two servos lying on the same floor wanted
  the same corner.)
- **Servo under the ceiling**, shaft along +X, case x 0…29, y 5…28, z 36.5…48.7.
  Below it the four-bar's upper links rise to z ≈ y + 5.7; that sets its height,
  and its top sets the cube.
- **The chain stacks back inboard under the servo's face.** The case ends at
  y = 27.8 and the chain lives further out in Y, so its X band is free: horn
  x 32.5…34.5 outboard of the face (spring between), then link1 and the lever's
  post (different Y) at 30…32, lever 26.5…29.5, link2 24…26, ear 20.5…23.5. The
  ear therefore lands beside the carriage's own +X arm and its bridge is a stub,
  rooted on the arm's 45° jog and ending in a block round the pin.
- The **servo bracket and the lever post mount to the ceiling**, not the wall.
  Screws into the ceiling are not modelled.
- Swept clearances over 9 tilts, pinned neighbours excluded: tightest **0.88 mm**
  (link1 vs spring), lever vs servo case 0.94, link1 vs case 1.00.

**Pick the servo on speed, not torque.** The binding spec is getting
free→contact done inside a push-off window of 50–150 ms: 20° is ~35 ms on an
MG90-class servo, full preload ~135 ms. Digital also matters for its small
deadband, because preload is set by small angle changes.

---

## 8. Torque estimate

Moment balance about the apex gives a closed form. The cube is **1:1** now (no
gear stage), so:

```
ΣN      = F_ear · y_ear / s̄
T_out   ≈ μ · F_ear · y_ear · sin β
```

The ear link pulls vertically, so its arm about the apex is simply its Y.

With μ = 1.3, y_ear = 42.9 mm, β = 33°: **≈ 0.030 Nm of output torque per newton
on the ear**; at the spring's 34 N, **≈ 1.0 Nm**. The overall cube ratio is
ω_out/ω_motor = sin α / sin β = **1.50** — an overdrive. The reduction the tree
needs (invariant 1) now has to live **between hubs**, and it has to beat that
1.5.

**Where the contact sits does not appear in that, and the cancellation is
exact.** Moments about the apex give `F·lever = ∫ n(s)·s ds`, because a force
perpendicular to the generatrix at distance `s` from the pivot has moment arm
exactly `s`. The output torque is `μ·∫ n(s)·(s·sin β) ds`, the same integral —
so `T = μ·sin β·F·lever` whatever the pressure distribution. Moving the rubber
outward buys friction radius and costs normal force in the same proportion.

So `lever / s̄` is **not** a torque multiplier. What it gives is the total NORMAL
force, which is what the rubber has to develop inside the available squeeze —
open question 1.

**This is an upper bound.** It assumes the rubber actually develops that normal
force within the available squeeze, which is exactly the unmeasured number below.
Do not quote it as fact.

Slip is a feature: it is a per-axis torque limiter and makes the joint
back-drivable, which matters for the passive-dynamics goal.

---

## 9. Why this design and not the alternatives

Recorded so they are not re-litigated. Each cost real time.

### Drive out of the cone

**Gear stage (pinion → idlers → corona, 1:3).** Worked, but asymmetric and
heavy on the packaging; removed. **Concentric pinion** before it: needs a free
gap angle of 10–12° whatever you do, because rotation moves the pinion ~3× faster
than the rubber (bound φc > 2·(Zc − Zp)·q / s̄, independent of where the pinion
sits). A beveloid pair has a working point at ~0.4 mm margin and module 0.85 —
rejected as too tight, not as impossible.

**Spline / crowned coupling, coaxial.** Assumed the axes only see an angle
because they cross at the apex. False: at the teeth (y ≈ 48) they are 2 mm apart,
and a spline cannot take offset — its side teeth would slide round the circle
while the top ones stay put. Modelled, rubbed 68 mm³.

**Corona on the cone shaft, always meshed; pinion/corona decoupled in free.**
Neither works; see the gear-stage note above.

**Double cardan, straight.** Works; ~40 mm long, the cube grows.

**Cardan + Oldham** (one joint per misalignment). Works, modelled on
`v7-cardan-oldham`; too long.

**Oldham alone.** Modelled on `v7-oldham`, 120.8 mm cube. Takes offset by
construction and 2.4° with 0.08 mm of flank room, but the disc nods ±0.46 mm once
a revolution, and it is a parallel-offset coupling asked to take an angle.

**Folded cardan with the tube on the cone and the crosses just past the carriage.**
Between the carriage (y 38) and the wall there is not enough length: the
intermediate has to rise ~20°, its corner reached the wall and the ring bore
rubbed the shaft. Moving the solid cross *into* the cone is what made it fit.

### Actuation

**Telescopic spring link from a crank on the floor.** Replaced: its crank ran
near dead centre, and with the smaller cube the servo landed on the lower link.
**Scotch yoke with slot and rail** before that. **Cam (disc or drum)** for a
variable ratio: unnecessary, the series spring already gives fast-then-powerful.

**Servo standing up in a corner.** Its horn turns in a horizontal plane and the
carriage moves in a vertical one: the linkage would need ball joints.

**Servo lying at mid-height in the side corner.** Lands on the neighbouring
axis' cone and carriage ring; the free band between them is 9.6 mm against a
12.2 mm case.

**Servo flipped (bottom to the neighbour's wall, shaft inward).** Its chain
would sit on the four-bar's upper links, and the ear would end up near the apex
with a ~4–7 mm horn.

**Turning alternate axes over.** Only needed while servos lay on the floor.

**Belt or pulley reduction at the joint.** Breaks the stacking symmetry.

**Flexure virtual pivot.** Deferred to v7 (PLA creep).

---

## 10. Open questions

1. **Rubber stiffness — the number everything hangs on.** How much normal force
   does a 2 mm rubber layer develop at ~0.2 mm of squeeze? Until this is measured
   the output torque is a guess. It decides the spring, the servo and whether
   the cones need to grow. No bench time for now: design for a range.
2. **Spring rate and spring_ratio.** The torsion spring (2.4 N·mm/°) is sized to
   the servo, not to the rubber; spring_ratio = 15 is invented.
3. **Making the rubber layer.** The flat pattern exists; wrapping it onto the
   cone is untested: adhesive, seam, thickness uniformity.
4. **Sizing, not layout.** Every pair of parts is checked at every stop, the
   links, the cardan and the actuation chain are swept as distances, and each
   axis is checked against its three neighbours. Nothing has been loaded, FEA'd
   or printed. Weakest-looking: the printed ring (pins at ~18 MPa, oscillating
   all the time), the output shaft's ~16 mm reach to the fork, the lever post
   from the ceiling.
5. **Central motor sizing.** Depends on (1) and on how many axes are engaged at
   once. Demands add, they do not divide.
6. **Where the reduction lives.** Each cube is now 1.5:1 overdrive; the chain
   between hubs has to supply the tree's reduction.

---

## 11. Next steps

1. Print one axis. Everything above is geometry that has never been in a
   printer: start with the cone + cardan + bearing, which is the new risk.
2. Model the ceiling screws for the servo bracket and the lever post, and size
   the torsion spring as a real part (wire, coils, legs).
3. Run the rubber measurement when there is time.
4. `cad/clutch_geometry_v6.html` is **stale** (telescopic link, gear front
   view): update or retire it before publishing.

---

## 12. Ideas raised 2026-09-15 — status

1. **Material at the cone tip.** Done: solid to y = 18.
2. **Four-bar links near the motor cone.** Checked by a swept distance (1.90 mm
   at the knuckle), not just at three stops.
3. **The rubber band's edge is not square.** Open.
4. **Get rid of the corona.** Done — replaced by the folded cardan (§6).
5. **Design the servo link for real.** Superseded — the telescopic link is gone
   (§7).

---

## 12b. The chain lost its lever (2026-09-20)

The five-pin chain (crank → link1 → lever 2.1:1 → link2 → ear) is now two
pins: a crank on the spline and ONE link to the ear. The user asked for the
simplification; nothing was given up for it.

- **Crank r 5.0**, perpendicular to the link at rest. Pointing it at the ear
  puts crank and link in line — dead centre, and at the far end of the stroke
  the chain cannot reach the ear at all. Perpendicular is where the
  transmission is: worst angle over the stroke 57.8°, against 41.7° before.
- **Effective radius at the ear 4.48 mm**, measured at the preload stop, where
  the old crank-and-lever gave 4.29. So the force at the ear is 32 N instead
  of 34, and the torque ceiling 0.98 Nm instead of 1.0. The spring, the sweep
  and the stops are unchanged; the sweep to contact (20.2°) is now DERIVED
  from the crank rather than being the input the crank came out of.
- **The link stacks OUTBOARD of the spring**, with the crank outermost. It
  cannot go inboard: with the crank perpendicular, the link's pin sits one
  crank radius from the spline, and the spring is wider than that — the joint
  itself lands inside the spring, so no shape of link gets round it. Growing
  the crank instead would have cost force at the ear in the same proportion,
  which is exactly what the lever was there to buy.
- **Cost: the carriage is 54 mm wide in X, against 45.** The ear follows the
  link's band outward. The cube does not change (106.5 — the cardan sets it),
  and the servo cannot move inboard to win it back: at 27 mm its case already
  overlaps the neighbouring axis' bracket on the shared ceiling.
- **Gone with the lever**: its ceiling post (one of the three brackets), link1,
  three pins and three E-clips.

## 12c. The servo stands in the corner (2026-09-20)

The user's layout, and it works: the servo STANDS (its 22.8 length into the
cube in Y, only 12.2 tall) down by the floor, turned so its shaft points −X
and its base ends beside the four-bar's own pin at x −12.5.

- **The chain gets a corner to itself.** Behind the shaft face there are
  7.8 mm to the neighbour's wall, and nothing else wants them: spring, link
  and crank fit with 0.26 to spare. Before, the same chain had to share
  8.8 mm with the four-bar's links, which is what left three 0.5 mm conflicts.
- **The ear rides over the servo.** Standing, the case is only 12.2 tall, so
  the carriage's ear bridge passes clear above it, out from the lower limb at
  z −24 to the link's plane at x −44.6.
- **No clips in the chain.** Every plate has a neighbour act_gap = 0.4 away
  and each pin engages a full plate thickness, so nothing can slide off — the
  stack retains itself, like the four-bar's straddled pins. Which is just as
  well: an E-clip needs 0.7 mm of free face and the corner has 0.4.
- Crank r 4.3, link 18.9, effective radius at the ear 4.19 mm (the old
  crank-and-lever gave 4.29): 34 N at the ear, 0.97 Nm ceiling — unchanged.
  Worst transmission angle 52.4°, against 44.9 before and 41.7 with the lever.
- **What it costs: the carriage is 66 mm wide in X**, against 43 with the
  servo lying under the wall, because the ear now reaches into the corner.
  That bridge is a 28 mm cantilever and NOTHING has checked its stiffness —
  it deflects straight into the preload. First thing to size.
- The cube is unchanged at 106.4, still set by the cardan.

## 12d. A lead screw instead of a linkage (2026-09-20)

The user's idea, and it holds up: the servo stands upright on the floor in the
corner with its shaft UP, turning a T8 lead screw; the nut rides up the screw
and pushes the ear on the carriage's arm. No crank, no link, no lever, no
change of plane — the problem every linkage kept running into was that all
its pins are parallel to X, and a screw does not care.

- **Servo** upright on a cradle printed with the FLOOR, x −31.2, y 39.5.
  **Screw** T8, lead 8 mm/turn, running up to a top bearing on a post printed
  with the WALL: the thrust is caught at both ends, never through the servo.
- **Ear at z +15**, high on the arm. Two things put it there: below z 14.4 the
  pusher would have to reach through the carriage's own ring, and below
  z −13 it would be inside the servo, which stands 32.2 mm tall.
- **Force 57 N at the ear** (2·π·τ·η/lead, η ≈ 0.5), against 34 from the crank
  chain, so the torque ceiling goes from 0.97 to **1.6 Nm**.
- **The travel budget is the tight part.** The ear is 43 mm from the apex and
  the free gap is 2°, so closing it eats 62° of the servo's 80. What is left
  is **0.40 mm of spring squeeze**, which needs a ~140 N/mm compression
  spring — stiff, and its tolerance is now what sets the preload. A coarser
  lead would fix it; T8-8 is the coarsest standard one.
- **The spring becomes a compression spring**, a catalogue part. That closes
  §13's question 5 (torsion spring: buy or design?) by making it moot.
- The ear's arc wanders **0.64 mm** off the nut's straight line over the
  stroke, so the pin needs a slot, not a hole. (An earlier estimate of
  0.04 mm was the departure from a straight line, not the Y component of the
  arc — the macro measures the real thing.)
- Carriage back to 43 mm in X, cube 106.1.

Not yet done: the nut's anti-rotation guide, the coupler from spline to
screw, and the spring's own seats.

### 12d.1 The spring cartridge (2026-09-20)

The series spring sits between the nut and the ear, and it has to push BOTH
ways, so it is two stacks with the moving part between them:

- The brass nut (bought) is gripped by a printed **cage**: a collar round it,
  a web down its motor side, and two **seat plates** reaching out to the guide
  rod, one above and one below.
- A **carrier** floats between those plates, sliding on the guide rod, and its
  arm reaches out to the ear's pin. It straddles the screw through a clearance
  hole — the rod is on one side of the screw and the ear on the other.
- A **spring stack** sits round the rod between each plate and the carrier.
  Push up and the top one is squeezed; push down, the bottom one.
- The web is **slotted** where the carrier passes, and that slot is what lets
  the carrier float; the plates are tied together by a spine beyond the rod,
  because the motor side is where the carrier's own arm runs.

Numbers: **0.40 mm of stroke, ~140 N/mm per stack, 57 N at the end of it**.
That is die-spring or Belleville territory; a plain coil spring that short
cannot reach the rate. Around the SCREW there is no room for any of this —
the wall is 7 mm away and the nut is 14 across — which is why the whole
cartridge lives round the guide rod instead.

Open: whether to give the stacks a light preload (~0.2 mm) so the carrier
does not rattle in free, and the actual catalogue part.

### 12d.2 Where each bracket is printed (2026-09-20)

The user's rule, and it is a better one than "everything on the wall":
**each bore goes on the part where it prints round.**

- The screw's top bearing and the guide rod's top anchor have **Z bores**, so
  they hang from the CEILING, which prints flat — the holes come out true.
- The servo's cradle has **Z screws** into its tabs, so it is part of the
  FLOOR, which the servo stands on anyway.
- The four-bar's frame posts have **X bores** for their pins. Printed with the
  wall those would be horizontal holes, which is where FDM goes oval, so they
  are printed SEPARATELY, laid bore-up. They are held by the DECKS, not the
  wall (user, 2026-09-21): each deck grows a solid block down (or up) to its
  post, and two short screws go in along Z from OUTSIDE the cube, heads sunk
  flush in the deck's outer face, and bite the post BESIDE the pin — one
  6 mm in front of it and one 6 mm behind, on the post's centreline — so they
  can go deep without meeting its bore. Right above the pin they would have
  had 2 mm of thread. The post runs back to the wall and forward by the same
  amount, symmetric about its pivot, with a straight 45° chamfer (3.5 mm legs) on
  its front edge, over the link's knuckle, which passes right under it. The deck's block is the post's
  own footprint and no wider.
- Only the guide rod's foot stays on the wall: it sits above the servo, where
  neither deck reaches it without passing through the case.

Falling out of it: the wall carries no screws at all now, and `both_hands()`
stopped mirroring the screw pattern — nothing is turned over any more, and
the mirrored half had landed in the actuation's own column.

### 12d.3 The carriage becomes a block (2026-09-21)

The user's idea, raised once before and not viable then — the block's corners
reach 29.6 from the axis where the ring reached 21.5, and in the old layout
those corners landed on the pusher, the servo and the screw's post. Since
then the guide rod moved 7.8 mm toward the motor (to keep the nut's flange
whole), which let it come 3 mm in toward the screw in X (they are at
different Y now), which pulled the cage off the carriage and gave the
corners their room.

- Block half-width 20.9: the least that keeps 2.2 mm of wall over the
  6805's seat on the flats.
- The ear is bored straight into the block's own −X face: no boss, no arm.
  The pin is pressed into it and runs in the carrier's slot; the carrier's
  arm, bush to pin, is 7.6 mm.
- The servo is modelled as it is: a main case 22.4 tall and a gear tower,
  12.2 long, over the shaft end only, up to 28.2. The end of the case nearest
  the carriage has no body above 22.4 — which is where the block's lower
  corner comes.

## 13. Next session — raised 2026-09-17, not yet worked

Notes as raised, not designs. Nothing here has been checked against the macro.

1. **DONE (2026-09-18): stop the carriage sliding sideways (in X).** It had
   ±2 mm (1.5 per side at B, 0.5 at A). An apex offset across the contact
   plane slips exactly like the four-bar's drift along it: δ / L, so 2 mm was
   ~8.7%, worse than v5. Now every thrust face (carriage arm boss at B, frame
   lug at A, top and bottom) is printed `shim_gap` = 0.3 short and filled with
   DIN 988 4×8 shims at assembly; target play ≤ 0.1 mm (0.43% slip, under the
   four-bar's 0.60). The foot's slot no longer grips the link at zero X
   clearance. Two checks: X play measured by nudging the solids, and its slip.
   Original note:
   **Stop the carriage sliding sideways (in X).** The four-bar only constrains
   the Y-Z plane; if the carriage can shift along the pivot pins, the cone's
   apex leaves the motor apex, and that is fatal to the whole geometry. Needs
   real axial location at the pins (shoulders, spacers, clips), not just
   clearance fits.
2. **DONE (2026-09-20): printed as part of their host, all three.** The user's
   call. The two frame posts are printed with the WALL (no foot, no screws —
   `wall_screws()` is empty now); the servo bracket and the lever post with the
   CEILING, one set per axis. Each runs `bracket_weld` = 1 mm into its host, so
   the fuse is a solid joint and not two solids sharing a face — checked, along
   with the host still being one solid and the ceiling's horn relief not eating
   a bracket. With the foot gone, the frame pins at A have a clear insertion
   path on their own. Original note:
   **Brackets: screwed to the wall, or printed as part of it?** Frame posts,
   servo bracket, lever post. Printing them on the wall saves screws and play;
   screwing them keeps the wall simple to print and the parts replaceable.
3. **Accumulated play in the actuation chain.** Horn → link1 → lever → link2 →
   ear is five pinned joints in series; their slop adds up and blurs how
   precisely servo angle sets the squeeze (torque control). Quantify it, and
   decide which joints need tight fits or preload.
4. **DONE (2026-09-18): how the pins stay in without dragging.** Every pin is
   pressed into one part and runs in the other, so it turns in one bore only
   and nothing clamps a joint. Four-bar: pressed into the middle part (lug at
   A, link at B); the part straddling it cannot come off, so no clip at all.
   Actuation chain (lap joints): pressed into link1 at H, the lever at I/P/O,
   the ear at E; the running plate is held by a DIN 6799 RS 2.3 E-clip 0.1 mm
   off its free face, side picked by a sweep (O's clip goes inboard). Found on
   the way: the frame pins at A could not be fitted (the foot sat across
   their path; now a channel through it); Ø3 running holes were modelled 3.2,
   which this printer makes ~2.7 (now 3.6, press 3.3 — verify on a coupon);
   the horn and link1 passed 0.21 mm under the ceiling unseen (decks now in
   the chain's sweep; 1 mm relief in the ceiling). Pins need grooves for the
   clips: buy grooved or cut them. Original note:
   **How the chain's pins stay in without dragging.** Retention (clips, heads,
   press on one side, captive between plates) that does not add friction to
   the joint.
5. **The torsion spring coupling at the servo: design it, or buy it?** Look for
   an existing part (servo saver without preload, spring hub) before designing
   one; if designing, size the spring as a real part (wire, coils, legs, how
   it is anchored to spline and horn).
6. **Inventory of materials and tools** needed to build one axis: purchased
   parts, pin stock, springs, screws, rubber, filament, drills, jigs.

## 14. A self-energizing clutch — analysis (started 2026-09-22)

**Why.** The user's original idea, from over twenty years ago: the torque itself
should tighten the clutch, so that *a stronger motor means more torque*. Today it
does not. The torque that passes is set by the servo's squeeze
(T = μ·sin β·M, §8), about ten times the clutch servo's own torque. A slow motor
with a lot of torque, which is how the user sees the central motor, cannot get
that torque through. Everything below is a first analysis on paper; nothing has
been modelled yet.

### 14.1 Why v6 does not self-energize

The contact force on the output cone has two parts, at a point
P = (0, y_c, z_c) on the shared generatrix, a distance s̄ from the apex
(y_c = s̄·cos β, z_c = ±s̄·sin β):

- the **normal** force N, in the tilt plane (Y-Z). Its moment about the tilt
  axis X is N·s̄, and that moment is what the actuation has to supply;
- the **friction** force f = μN, along X. The motor cone's surface at P moves at
  ω ẑ × P = (−ω·y_c, 0, 0), so the output cone is dragged toward −X, and **at
  the same point for both motor cones**, because they turn the same way.

The moment of f about the apex is P × (−f, 0, 0) = (0, −z_c·f, +y_c·f):

- about **X**, the tilt axis: **zero**. Friction does nothing to the tilt, and
  that is why there is no self-energizing today.
- about **Y**, roughly the output axis: −z_c·f. This is the torque the load
  takes. It changes sign between the upper and lower cone, as it should,
  because the output reverses.
- about **Z**, the motor axis: **+y_c·f = μ·N·s̄·cos β, the same sign for both
  cones.** This is a yaw moment on the carriage. Today the four-bar and its X
  shims take it and it goes nowhere.

### 14.2 Mechanism A — let the carriage yaw about the motor axis, on a chevron

Give the carriage a second rotation, **yaw ψ about Z through the apex**, and
guide it so that yawing also tilts it further into whichever cone it is
touching: dθ/dψ = +k on the upper branch and −k on the lower. The path is a
"<" with its vertex stretched into a straight segment. The segment is the free
travel, ±φc along ψ = 0, which the servo drives. At **each** contact point a
spiral branch leaves toward the same side (+ψ): one climbs toward the upper
cone, the other descends toward the lower. Friction carries the carriage along
whichever branch it is on (the user's picture, 2-DOF about the apex: tilt, and
a spiral rotation about the motor axis).

- **The apex does not move.** Every rotation about an axis through the apex
  keeps it fixed, so the three cones keep one apex and still roll without
  slip. Yaw only carries the contact line round the motor cone. The folded
  cardan (§6) takes the small change of angle.
- **Balance (virtual work along a branch, dθ = k·dψ):**
  M_s·dθ + μN·s̄·cos β·dψ = N·s̄·dθ, which gives

      N·s̄·(1 − G) = M_s      with   G = μ·cos β / k

      T = μ·sin β·M_s / (1 − G)

  The servo supplies only the fraction (1 − G) of the squeeze. The clutch
  passes 1/(1 − G) times what it does today, **and the squeeze grows with the
  torque asked for**, so a stronger motor pushes more torque through.
- **Stability.** It needs G < 1. At G ≥ 1 the squeeze runs away on its own
  once the cones touch, and releasing it would take a pull back proportional
  to the torque being passed, which a small servo cannot give (§14.4). G moves
  with μ, so k has to be set against the **largest** μ expected.

With β = 33° (cos β = 0.839), G and the gain 1/(1 − G) come out as:

| k | μ = 1.0 | μ = 1.3 | μ = 1.6 |
|---|---|---|---|
| 1.6 | 0.52 → ×2.1 | 0.68 → ×3.1 | 0.84 → ×6.2 |
| **1.7** | **0.49 → ×2.0** | **0.64 → ×2.8** | **0.79 → ×4.8** |
| 1.8 | 0.47 → ×1.9 | 0.61 → ×2.5 | 0.75 → ×3.9 |
| 2.0 | 0.42 → ×1.7 | 0.55 → ×2.2 | 0.67 → ×3.0 |

A first pick is **k ≈ 1.7**: G stays under 0.8 even at μ = 1.6, and the gain
is ~×2.8 at the nominal μ = 1.3. The spread of the gain with μ (×2 to ×4.8)
means the torque for a given servo angle depends on the state of the rubber.
Torque control needs the AS5600 and a model of μ, or a closed loop on output
speed.

- **Overrun and braking.** If the load drives the output (lowering a limb,
  braking a swing), the friction reverses, so does the yaw moment, and the
  carriage is pushed back toward the vertex. The clutch is then *weaker*:
  T = μ·sin β·M_s/(1 + G), ×0.61 at G = 0.64. It frees itself rather than
  locking, like a freewheel, which is safe. But it means **the clutch cannot be
  a strong brake**, so the fourth state (the brake/lock) still has to be its
  own mechanism.
- **Scale of the motion — the hard part.** The whole squeeze is
  δφ ≈ 0.046° of tilt (contact 2.0°, preload 2.046°), so the yaw along a
  branch is δψ = δφ/k ≈ 0.027°: **~0.02 mm at the carriage pivots' radius
  (40.5)**. Any compliance or play in the guide that is not small against the
  rubber's eats the ramp. Two things help:
  - the yaw moment has **one sign** whenever the clutch drives, so the carriage
    always leans on the same face of the guide, and the play there is taken up
    rather than crossed (the X shims' ≤ 0.1 mm stops mattering in that
    direction);
  - the guide can be a **flexure**, with no pivot play at all.

  The guide has to be stiff *compared with the rubber*, which is one more
  reason to measure the rubber first.
- **Actuation stays force-type.** Self-energizing needs the tilt free to follow
  the ramp beyond where the servo put it. The series spring (§12d.1) already
  makes the actuation a force source, not a position, so it fits. Its own
  stiffness adds a small restoring term that lowers G slightly: a safe error.
- **What it asks of the mechanism.** The four-bar today is planar: one degree
  of freedom, tilt about X, with a virtual pivot. Mechanism A needs **two**,
  tilt and yaw about a virtual spherical pivot at the apex, constrained to the
  chevron. That is the real design work.

### 14.3 Mechanism B — a V ball-ramp in the output drive

The classic torque-sensing clutch: a ball-ramp with **V-shaped** grooves
between the output cone and the cardan. Torque of either sign rides the balls
up the V and pushes the cone along its own axis, toward the apex, pressing both
contacts. It is a known, compact part and needs no new degree of freedom on the
carriage. Its cost: moving the cone along its axis moves its apex. The squeeze
(~0.2 mm normal) takes ~0.2/sin β ≈ 0.37 mm of axial travel, so an apex error
of ~0.37 mm and ~1.6% micro-slip over the 23.4 mm band, against 0.60% for the
four-bar's drift today (§5). That breaks invariant 2 a little. It has to be
weighed against A's difficulty.

### 14.4 Why G ≥ 1 cannot simply be "held by the servo"

For G > 1 the balance is N·s̄·(1 − G) = M_s with (1 − G) < 0: holding a given
squeeze needs the servo to **pull back** by (G − 1)·N·s̄. That grows with the
torque being passed, so it is unbounded for a strong motor, and the
equilibrium is unstable without active control. Drum brakes run high G (duo
servo) but always below 1, and so must this.

### 14.5 Next steps

1. Measure μ (dry, dusty, damp) and the rubber's stiffness on a one-axis bench.
   The same bench is needed for §10's open question anyway.
2. Decide A or B. For A, sketch a two-DOF guide about a virtual spherical pivot
   (flexures, or a four-bar with a skewed chevron cam), and check its
   compliance against the rubber's.
3. Model the chosen one in the macro: the yaw sweep, the branches and a check
   on G at μ_max.
4. Only then change the cube. The rest of it (column, walls, dogs, stacking,
   screw actuation) is unaffected.

## 15. What gets built — state at 2026-09-22

The cube as it stands in the macro (31 checks green), to be built as is while
§14 is investigated. It supersedes the actuation in §7 and the cube sizes in
§12. The parts to buy are in `docs/bom-v6.md`.

### 15.1 Actuation, one axis

1. **Servo.** An MG90D stands on the floor in the axis' own corner, shaft up.
   Its cradle is printed with the wall and has a cable pocket on the shaft
   end, open toward the motor.
2. **Horn and coupler.** The servo's double horn, its arms cut to 11 mm tip to
   tip (the coupler sweeps ±80° and the wall is 7.6 mm off the axis), sits in
   a pocket in the printed coupler. It drives by its shape and is **free in
   Z**, so the servo never takes thrust. Its own M2.5 screw holds it on the
   spline, through the coupler's floor.
3. **Lead screw.** A T8, lead 8 (4 starts), gripped on its thread by the
   coupler's M3 grub. It is guided at the top by the ceiling's screw-top post
   and at the bottom by the thrust plate.
4. **Thrust stop.** The guide rod's foot runs on round the screw as a 4 mm
   plate: coupler | PTFE 8×12×1 | plate | PTFE | T8 lock collar. It stops both
   directions, and the washer's friction (~0.03 Nm) is counted in the force.
5. **Nut and cage.** The CESFONJER kit's rectangular-flange brass nut (22 ×
   10.5 × 4, 2× M3×10) is screwed on top of the spring cage. The cage slides on
   the Ø4 guide rod, which stops it turning.
6. **Series spring.** Inside the cage a carrier floats on the rod between two
   spring stacks (Ø11/Ø5, ~72 N/mm, part not chosen). The carrier is one block
   from the rod to the carriage.
7. **Ear.** A Ø3×14 dowel pressed 8.6 mm into the carriage block's −X face runs
   5 mm into the carrier's blind slot, free in Y (it swallows the ear's arc)
   and tight in Z (the load path).

The servo turns ±80°. About 59° close the free gap (1.3 mm of nut travel) and
the rest compresses the spring 0.48 mm. With 60% of the MG90D's 0.18 Nm
(derated for cheap servos and supply sag), the force at the ear is **34 N**:
1.30 Nm about the apex, an output torque ceiling of **~0.92 Nm** at μ = 1.3.
The lead screw almost holds itself (back-driving ~0.01 Nm, less than the
washer's friction), so the servo spends torque on moving, not holding.

### 15.2 The central column

- **Shaft.** A bought Ø8 D-shaft (7.5 across the flat), 105 mm, on two 688ZZ.
  Each bearing sits on a 1 mm lip just inside its deck's dog hole; the bottom
  one stands in a boss.
- **Cones.** Each motor cone is keyed on the flat by its own printed D bore,
  tip to base. No flanges.
- **Spacers.** A printed spacer from each cone's base to its bearing's inner
  race takes that cone's thrust. The contact only ever pushes a cone away
  from the apex, so this stop carries the load by bearing on it, not by a
  grub's friction. The spacers' lengths set the cones' height, and so the
  apex: print them to length or shim them.

### 15.3 Cube to cube

- **Faces.** Five identical male outputs (top and the four walls) and one
  female input (bottom). Every face also carries a 34×3 square spigot or its
  socket, which centres the cubes and carries the reaction torque in 90°
  steps, and four N52 10×2 magnets at (±40, ±40). A hard knock pulls the cubes
  apart, which is wanted.
- **Dogs.** Printed parts keyed on the shafts' D by an M3 grub:
  - the male has three 44° claws with narrowed tips and a core;
  - the female has three claws and a free middle;
  - a TPU spider has six arms and an outer ring.
  
  The input dog carries ~1.1 Nm, and that caps the whole cube. Its grub is
  tightened on the bench, and the shaft goes in from below with the dog on it.

### 15.4 The case

A **106.1 mm cube** with 4 mm faces, grown back from the 122 mm version. The
decks get their stiffness from four 12 mm ribs, one in each axis' plane, from
the bearing boss to the four-bar posts' pads. The ribs clear the links by
~3.5 mm over the stroke and bend ~0.007 mm with all four axes on one cone.
Each wall is held by 4 M3×10 countersunk screws from outside, two into the
ceiling and two into the floor (16 in all), so the stacking faces stay flat.
The whole cube weighs **~1.0–1.15 kg** by the model, without the central motor.

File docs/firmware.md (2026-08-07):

# Firmware Guide — Motcore v0.1

---

## Architecture

The control system uses two Arduino Uno boards communicating over serial:

```
┌─────────────────────────────┐     Serial      ┌─────────────────────────┐
│     Master Arduino          │ ──────────────► │    Receiver Arduino     │
│                             │                  │                         │
│  - TFT Touchscreen UI       │                  │  - Stepper motor control│
│  - Servo control (4 axes)   │                  │  - Receives commands    │
│  - User input processing    │                  │    from master          │
└─────────────────────────────┘                  └─────────────────────────┘
```

---

## Repository Structure

```
src/
├── controller/          # Master Arduino firmware
│   ├── controller.ino   # Main file
│   └── ...
└── driver/              # Receiver Arduino firmware
    ├── driver.ino        # Main file
    └── ...
```

---

## Dependencies

### PlatformIO (recommended)

Dependencies are declared in `platformio.ini`. Run:

```bash
pio lib install
```

### Arduino IDE

Install the following libraries via Library Manager:

| Library | Purpose |
|---|---|
| `MCUFRIEND_kbv` | TFT display driver |
| `Adafruit GFX` | Graphics primitives |
| `TouchScreen` | Touchscreen input |
| `Servo` | Servo motor control |
| `AccelStepper` | Stepper motor control |

---

## Upload Instructions

> **Important:** Disconnect the TX/RX serial wires between the two Arduinos before uploading, then reconnect after.

### 1. Upload to Master Arduino

```bash
# PlatformIO
cd src/controller
pio run --target upload

# Arduino IDE
# Open src/controller/controller.ino
# Select board: Arduino Uno
# Select port: COM port of master Arduino
# Click Upload
```

### 2. Upload to Receiver Arduino

```bash
# PlatformIO
cd src/driver
pio run --target upload

# Arduino IDE
# Open src/driver/driver.ino
# Select board: Arduino Uno
# Select port: COM port of receiver Arduino
# Click Upload
```

---

## Serial Protocol

The master sends single-byte commands to the receiver over serial at **9600 baud**.

| Command | Action |
|---|---|
| `'F'` | Stepper forward |
| `'B'` | Stepper backward |
| `'S'` | Stepper stop |

---

## Servo Positions

Each servo has three positions:

| State | Angle | Description |
|---|---|---|
| Neutral | 90° | No contact with central shaft |
| Engage CW | 0° | Friction contact — clockwise rotation |
| Engage CCW | 180° | Friction contact — counterclockwise rotation |

These values can be tuned in `controller.ino` based on your physical assembly.

---

## Customization

### Changing servo angles

In `controller.ino`, adjust the `SERVO_NEUTRAL`, `SERVO_CW`, `SERVO_CCW` constants to match your mechanical setup.

### Adding more axes

1. Connect additional SG90 servos to available PWM pins
2. Add servo objects and pin definitions in `controller.ino`
3. Add corresponding UI buttons to the touchscreen layout

### Changing stepper speed

In `driver.ino`, adjust the `STEPPER_SPEED` constant (steps per second).

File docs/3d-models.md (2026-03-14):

# 3D Models — Motcore v0.2

> **Status:** 🔄 In development. This page will be updated as models are completed.

---

## Overview

Version 0.2 replaces the LEGO Technic proof-of-concept with parametric 3D-printed components designed in **FreeCAD**. The goal is a reproducible, printable design using standard mechanical components (bearings, smooth rods, O-rings).

---

## Design Principles

- **Parametric** — all key dimensions are driven by a spreadsheet in FreeCAD, making it easy to adapt to different motor sizes or axis counts
- **Print-in-place friendly** — minimize post-processing and hardware inserts
- **Standard components** — use off-the-shelf bearings, rods, and O-rings where possible
- **Compliant mechanisms** — the friction engagement system uses flexure-based compliance instead of rigid joints

---

## Planned Components

| Component | Status | File |
|---|---|---|
| Central motor mount | 🔄 In progress | `cad/MotorMount.FCStd` |
| Friction wheel (TPU) | ⬜ Planned | — |
| Output axis carrier | ⬜ Planned | — |
| Servo bracket | ⬜ Planned | — |
| Main frame | ⬜ Planned | — |
| Engagement arm (compliant) | ⬜ Planned | — |

---

## Software Requirements

- [FreeCAD](https://www.freecad.org/) 0.21 or later
- No additional workbenches required for basic parts
- **Lattice2** workbench recommended for array operations

---

## Printing Recommendations

| Parameter | Recommendation |
|---|---|
| Layer height | 0.2mm |
| Infill | 40% (structural parts), 20% (brackets) |
| Material (rigid parts) | PLA or PETG |
| Material (friction wheels) | TPU 95A |
| Supports | Only where indicated |

---

## Contributing CAD Models

If you'd like to contribute FreeCAD models:

1. Use the existing parametric spreadsheet as the source of truth for dimensions
2. Follow the naming convention: `ComponentName_vX.X.FCStd`
3. Export a STEP file alongside the native FreeCAD file
4. Include a screenshot in `docs/images/`
5. Open an issue before starting major design work to avoid duplication

---

> 📷 Render images and assembly animations will be added here as the design matures.

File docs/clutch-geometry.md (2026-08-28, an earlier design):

# Motcore v5 Clutch — Geometry & Equations

The interactive visualiser is at `cad/clutch_geometry_v5.html`. This document
derives the equations implemented there.

For the four superseded generations that led here, see
[design-evolution.md](design-evolution.md). The v2 bevel derivation is archived
at [archive/clutch-geometry-bevel.md](archive/clutch-geometry-bevel.md).

---

## 1. Design intent

A single vertical motor shaft must drive several output shafts, each of which
feeds the **next hub of an actuator tree**. Three requirements, in order of how
hard they were to satisfy:

1. **Real free rotation.** A disengaged axis must carry *nothing* — not a small
   residual friction, nothing. An arm has to be able to fall under its own
   weight. This is what killed every previous generation.
2. **Reduction at every level.** Torque is consumed going down the tree and has
   to be regenerated at each stage. Speed is the surplus resource.
3. **Torque limiting per axis**, settable in software.

v5 answers (1) with geometry rather than friction, (2) with an internal gear
stage, and (3) with the friction stage it already needed.

---

## 2. Architecture

- **Two motor cones** — on the central vertical shaft (Z), fixed, rotating
  continuously, facing **apex to apex** (an hourglass with a waist at the
  mid-plane). The lower has its apex up and flares downward; the upper is the
  same part fitted upside down.
- **Output cone** — one per axis, in that waist, on a **carriage that
  translates vertically** on two 3 mm guide rods. No tilt, no pivot, no
  universal joint. One degree of freedom.
- **Output shaft** — horizontal, fixed, perpendicular to the motor axis, at the
  mid-plane, with the apexes nominally common with whichever cone is engaged.
- **Friction contact** — interleaved rubber O-rings on both cones, meeting
  flank to flank.
- **Gear stage** — a pinion rigid to the output cone, permanently inside an
  internal corona (ring gear) fixed to the output shaft.
- **Four axes**, one per cube wall.

### 2.1 Two cones = one bidirectional axis

The second cone is not a second set of axes. Both motor cones turn with the
motor, always the same way, but their flanks face **opposite sides of the
output axis**. Move the carriage down and the output cone's lower flank meets
the lower motor cone; move it up and its upper flank meets the upper one — and
the output shaft turns **the other way**.

One motor, one axis, both directions, without ever reversing the motor. It is
the conical descendant of v3/v4's "one disc, two usable faces" (see
[design-evolution.md](design-evolution.md)), and it is why **free sits in the
middle of the travel** rather than at one end.

The internal mesh is indifferent to the sign: the pinion is captive inside the
corona and meshes at whatever azimuth it is offset to, up or down.

---

## 3. Coordinate system

The geometry is described in the Y-Z cross-section: the vertical plane
containing both the motor axis and the output shaft axis.

```
Z (up)
│         ┌───┐  ← output cone on the carriage
│        ╱     ╲    (translates vertically ↕)
│       │  ○ ○  │ ── output shaft (fixed) + internal corona
│     ╱ ╲╲     ╱╱
│    ╱ ○ ┴╲───╱  ← O-rings interleaved, flank to flank
│   ╱──────╲
│    motor cone
└──────────────────────────── Y (horizontal, toward the wall)
     motor axis at Y = 0
```

- **Z** = motor shaft, vertical, upward. Motor axis at Y = 0.
- **Y** = horizontal, from the motor axis toward the wall / output shaft.
- Carriage height reference: **free = 0**, the mid-plane between the two motor
  cones. Down is negative, up positive, and the stop ladder is symmetric.
- The output shaft axis is fixed at `z = 0`, so the pinion is concentric with
  the corona at rest, in position 1.

---

## 4. Free parameters

```
α   — motor cone half-angle from the vertical axis (default 55°)
m   — gear module (default 1.0)
Zp  — pinion teeth, on the output cone / carriage (default 14)
Zc  — corona teeth, on the output shaft (default 28)
L   — contact line length along the generatrix (default 18 mm)
s₀  — apex → start of the contact line (default 10 mm)
d   — O-ring wire diameter (default 2.5 mm)
n   — rings on the motor cone; the output cone carries n − 1 (default 5)
g   — margin from full mesh to rubber contact (default 0.20 mm)
δ   — preload travel past contact (default 0.25 mm)
```

Everything else is derived.

---

## 5. Cone angles

The two shaft axes are perpendicular and the apexes are common, so:

```
α_out = 90° − α_motor
```

At α = 55° the output cone half-angle is 35°.

---

## 6. Transmission ratio

The friction stage ratio follows from the two cone radii at any point on the
shared generatrix. Because both radii scale linearly with distance from the
common apex, the ratio is **independent of position along the contact line** —
which is exactly why the common apex matters:

```
ratio_fric = sin(α_m) / sin(α_o)
```

The gear stage is an internal mesh, pinion driving corona, so it reduces:

```
ratio_gear = Zp / Zc
```

```
ratio_total = ratio_fric · ratio_gear
```

At defaults: 1.428 × 0.500 = **0.714**, i.e. ω_out = 0.714 · ω_motor and
**1.40× torque**. `ratio_total > 1` means the design is multiplying speed and
losing torque — the visualiser flags it.

---

## 7. The gear stage and the vertical ladder

The pinion never leaves the corona; only the **centre distance** changes as the
carriage descends. At mesh:

```
e = m · (Zc − Zp) / 2
```

Tip radii are `r_tip,p = m·(Zp/2 + 1)` for the pinion and
`r_tip,c = m·(Zc/2 − 1)` for the corona, so the gap before the first tooth can
touch anything is:

```
free float  = r_tip,c − r_tip,p = e − 2m
mesh travel = 2m
```

That gives four stops. `z` is measured from the mid-plane, where the output
shaft and its corona sit, so **free is z = 0** and the same ladder runs both
ways — only the sign changes:

| # | Position | \|z\| of the output cone axis | State |
|---|---|---|---|
| 1 | **Free** | `0` | pinion concentric, rings separated, output shaft drives nothing |
| 2 | **Mesh** | `e` | centre distance reached, rings **still separated**, relative velocity zero → teeth engage without shock |
| 3 | **Contact** | `e + g` | rubber flanks touch, normal force zero |
| 4 | **Preload** | `e + g + δ` | flanks compressed, torque transmitted |

Negative `z` engages the lower motor cone, positive the upper one.

```
stroke = e + g + δ                (half stroke, free → preload one way)
travel = 2 · (e + g + δ)          (full, down to up)
```

At defaults: e = 7.20, free float 3.60, mesh travel 3.60, **stroke 7.65 mm**,
full travel **15.30 mm**.

### 7.1 Where the motor cones sit — derived, not chosen

Each motor cone's apex must be exactly where the output cone's apex lands at
**contact** on that side. That is what makes the two apexes common, which is
the entire basis of the matched-surface-speed contact of §6. So the apex
separation falls out of the gear stage and is not a free parameter:

```
motor cone apexes at  z = ± (e + g)
separation          = 2 · (e + g)
```

At defaults the apexes sit at z = ±7.40 mm, 14.80 mm apart.

The order of stops 2 and 3 is not negotiable. Teeth must be fully meshed
*before* the rubber starts turning the output cone, or they clash at speed.

---

## 8. Preload and root clearance

Past position 3 the carriage keeps travelling by δ to compress the rubber
flanks. The pinion therefore sits δ + g past the nominal centre distance, and
that overshoot has to fit in the gear's own **root clearance**:

```
c = 0.25 · m

g + δ ≤ c            [constraint]
```

This is why there is no slot, no floating ring and no compliant blade — the
gear already has the compliance the preload needs.

**Resolved (was open).** The constraint is really a floor on the module:
`m ≥ 4·(g + δ)`. It was violated at the original m = 1.0 (`0.45` against
`c = 0.25`); the module is now **1.8**, the smallest value that satisfies it,
giving `c = 0.45` exactly. It holds with **zero margin** — any tolerance that
has to be absorbed here means raising `m` (and with it the whole gear stage).

---

## 9. Ring interleaving

`n` rings sit on the motor generatrix and `n − 1` on the output generatrix,
offset by half a pitch. Counting both sets, N = 2n − 1 rings share the contact
line, so the **alternating** spacing is:

```
q = L / (2n − 2)
```

For two adjacent rings of wire diameter `d` to touch flank to flank, their
centres must be closer than `d` measured along the line:

```
q < d                [constraint]
```

If `q ≥ d` the flanks never reach each other and no torque passes at all.

When they do touch, the two generatrices are pushed apart by the normal offset:

```
h = √(d² − q²)
```

which separates the two apexes along the motor axis by:

```
apex separation = h / sin(α_m)
```

and that separation is what breaks the common-apex condition, producing
**micro-slip** along the contact line:

```
micro-slip ≈ apex separation / L
```

At defaults: q = 2.25 mm < d = 2.5 mm ✓, apex separation 1.33 mm,
micro-slip ≈ 7.4 %.

> **Open — narrow window.** More rings interdigitate better but push the cones
> further apart:
>
> | n | q | flanks touch? | micro-slip |
> |---|---|---------------|------------|
> | 3 | 4.50 mm | ✗ (q > d) | — |
> | 5 | 2.25 mm | ✓ | 7.4 % |
> | 7 | 1.50 mm | ✓ | 13.6 % |
>
> Needs a sweep over `L` and `d`. Catalogue O-rings fix the available `d`, and
> the resulting pitches then have to land on the generatrix.

---

## 10. Internal mesh interference

An internal pinion/ring pair with too small a tooth-count difference fouls on
assembly and during rotation:

```
Zc − Zp ≥ 8          [constraint]
```

At defaults 28 − 14 = 14 ✓.

---

## 11. Transmitted torque

Torque is set by the **radial preload between rubber flanks**, with μ ≈ 1.2–1.5
for rubber on rubber — against 0.6–0.9 for the rubber-on-plastic contact of the
earlier generations. Because preload is radial and not axial, it is decoupled
from apex displacement: pushing harder does not require the cones to move into
each other.

The friction stage is also a **per-axis torque limiter**. It slips above the
preload-set threshold, the preload is set by carriage position, and carriage
position is software — so each axis can cap its own slip torque.

---

## 12. Summary of constraints

| # | Constraint | At defaults |
|---|---|---|
| 1 | `ratio_total < 1` — reduction, never 1:1 | 0.714 ✓ |
| 2 | Mesh before rubber contact (`\|z_mesh\| < \|z_contact\|`) | 0.20 mm ✓ |
| 3 | `g + δ ≤ 0.25 · m` — root clearance | 0.45 vs 0.45 ✓ **zero margin** |
| 4 | `q < d` — flanks can touch | 2.25 < 2.5 ✓ |
| 5 | `Zc − Zp ≥ 8` — internal mesh interference | 8 ✓ **zero margin** |
| 6 | AS5600 on every output shaft (structural, not optional) | — |
| 7 | Rubber on rubber only, never rubber on plastic | — |

The FreeCAD macro re-checks all of these on every run and prints the result,
along with solid-interference checks between adjacent axes and between the
output cone and the idle motor cone.

---

## 13. Default parameter values

| Parameter | Value | | Derived | Value |
|---|---|-|---|---|
| α | 55° | | friction ratio | 1.428 |
| m | 1.8 mm | | gear ratio | 0.500 |
| Zp / Zc | 8 / 16 | | **total ratio** | **0.714** (1.4× torque) |
| L | 18 mm | | centre distance `e` | 7.20 mm |
| s₀ | 10 mm | | free float | 3.60 mm |
| d | 2.5 mm | | mesh travel | 3.60 mm |
| n | 5 | | **half stroke** | **7.65 mm** |
| g | 0.20 mm | | **full travel** (down..up) | **15.30 mm** |
| δ | 0.25 mm | | motor cone apexes | ± 7.40 mm (sep. 14.80) |
| | | | ring pitch `q` | 2.25 mm |
| | | | ring-induced apex offset | 1.33 mm |
| | | | micro-slip | ≈ 7.4 % |

**Why m = 1.8 and only 8/16 teeth.** The root-clearance constraint sets a floor
on the module regardless of tooth count: `m ≥ 4·(g + δ) = 1.8`. Going above that
floor only bloats the gear stage — at m = 2.0 with 14/28 teeth the corona came
out *larger than the motor cone itself*, which defeats the point of the vertical
cone. At the floor, fewer teeth is the remaining lever to shrink it (radius
scales with `m·Z`), down to the interference floor of `Zc − Zp = 8`. Both
constraints now sit at zero margin, so neither can absorb a tolerance: if real
parts need headroom, `m` has to move first.

---

## 14. Position feedback is structural

Friction slip accumulates non-repeatably in series along a tree. Commanded
position is therefore not knowable by dead reckoning — it has to be **measured**
at every output shaft. An **AS5600** magnetic encoder on each output shaft is
part of the mechanism, not an optional extra.

Its I2C address is fixed at **0x36**, so multiple encoders require multiplexing:
analog output, PWM, or a TCA9548A.

Firmware also needs the encoder *before* engaging: re-meshing while the output
shaft is still turning (an arm falling, say) clashes teeth. A velocity check via
the AS5600 has to gate the transition into position 2.

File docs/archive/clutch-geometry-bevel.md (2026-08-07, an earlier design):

# Motcore Bevel Clutch — Geometry & Equations (v2, ARCHIVED)

> **⚠️ Superseded.** This document describes the **v2 bevel cone** generation
> (May 2026), two generations behind the active design. It is kept for the
> record only — do not build from it and do not re-propose the tilting-shaft
> family it belongs to.
>
> - Active geometry: [../clutch-geometry.md](../clutch-geometry.md) (v5)
> - Why it was superseded: [../design-evolution.md](../design-evolution.md)

The interactive visualizer for this generation is at `cad/clutch_geometry.html`.
This document derives the equations implemented there.

---

## 1. Design intent

A single Z-axis motor must drive output shafts along ±X and ±Y. Each output
shaft has a **bevel cone friction clutch**: a truncated cone mounted on the
output shaft that, when the shaft is tilted by a servo, makes surface contact
with the motor cone on the Z shaft and transmits torque by friction.

The design goal is **generator-line contact** — both cones share a common apex
and are tangent along a common generator line.

---

## 2. The four free parameters

```
A  — engagement angle (degrees): how much the servo tilts the output shaft
B  — arm length (mm): distance along the output shaft from UJ pivot to the
     large face of the clutch cone
C  — clutch cone large-face radius (mm)
D  — motor cone large-face radius (mm)
```

All other dimensions are derived from these four.

---

## 3. Coordinate system

The geometry is described in the Y-Z cross-section:

```
Z (up)
│                     ╔═══════╗
│             apex ●──╢ motor ╟── input shaft at y = L
│            ╱    └───╚═══════╝
│           ╱  ← contact edge (red)
│          ╱ ← clutch cone (tilted A° from horizontal)
│─────────●──────────────────── Y (horizontal)
│        UJ pivot (origin)
```

- **UJ pivot** = world origin (y=0, z=0)
- **Y** = horizontal, pointing toward the input shaft
- **Z** = vertical, pointing up (input shaft direction)
- **Input shaft** sits at a horizontal distance L from the UJ (derived)

---

## 4. Deriving L — the key constraint

When the output shaft is tilted by angle A, the clutch cone large face is at:

```
lfc_y = B·cos(A)
lfc_z = B·sin(A)
```

The perpendicular to the shaft axis (pointing toward the motor) is (−sin A, cos A).
The contact edge endpoint (where the clutch cone large face meets the motor cone) is:

```
contact_y = B·cos(A) − C·sin(A)
contact_z = B·sin(A) + C·cos(A)
```

For this point to lie on the motor cone large face, which has radius D centred
on the input shaft at y = L, we need:

```
contact_y = L − D
```

Therefore:

```
L = D + B·cos(A) − C·sin(A)          [Key derived dimension]
```

L is not a free parameter — it is fully determined by A, B, C, D.

---

## 5. Shared apex position

The output shaft axis, tilted by A from horizontal, passes through the UJ origin
with slope tan(A). It meets the input shaft (vertical line at y = L) at:

```
apex_y = L
apex_z = L · tan(A)                   [Shared apex]
```

Both cones have their apex at this point.

---

## 6. Motor cone geometry

The motor cone's large face is horizontal at height contact_z, centred on the
input shaft. Its height (from apex to large face) is:

```
h_motor = contact_z − apex_z
        = B·sin(A) + C·cos(A) − L·tan(A)
```

---

## 7. Cone half-angles

```
dist_apex_lfc = √[(lfc_y − apex_y)² + (lfc_z − apex_z)²]

α_clutch = arctan( C / dist_apex_lfc )
α_motor  = arctan( D / h_motor )
```

---

## 8. Bevel condition

For generator-line contact, the sum of the two half-angles must equal the angle
between the shaft axes:

```
α_clutch + α_motor = 90° − A          [Bevel condition]
```

**This is automatically satisfied** by the shared-apex construction — you do not
need to check or enforce it. Choosing any A, B, C, D and computing L as above
guarantees the bevel condition holds.

---

## 9. Self-locking condition

With a conical surface, friction has a component along the cone axis. Self-locking
occurs when the servo cannot disengage the clutch:

```
μ ≥ tan(α_clutch)    ← self-locked, cannot disengage

μ < tan(α_clutch)    ← safe, servo can disengage
```

At small A (e.g. 8°), α_clutch is large (~49°), so tan(α_clutch) ≈ 1.1 — well
above any practical friction coefficient. Self-locking is not a concern at small
engagement angles.

---

## 10. Summary table

| Quantity | Formula |
|---|---|
| L (UJ to input shaft) | D + B·cos(A) − C·sin(A) |
| Apex position | (L, L·tan(A)) in (y, z) |
| Contact point | (L−D, B·sin(A)+C·cos(A)) |
| Motor cone height | B·sin(A) + C·cos(A) − L·tan(A) |
| α_clutch | arctan(C / dist(apex, lfc)) |
| α_motor | arctan(D / h_motor) |
| Bevel condition | α_clutch + α_motor = 90° − A (auto) |
| Self-locking limit | μ < tan(α_clutch) |

---

## 11. Default parameter values

| Parameter | Value |
|---|---|
| A | 8° |
| B | 35 mm |
| C | 9 mm |
| D | 9 mm |
| L (derived) | ≈ 42.4 mm |
| apex_z (derived) | ≈ 6.0 mm |
| h_motor (derived) | ≈ 7.8 mm |
| α_clutch ≈ α_motor | ≈ 49° |

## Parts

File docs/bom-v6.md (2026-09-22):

# Motcore v6 — bill of materials, one cube (4 axes)

State of the macro at 2026-09-22 (`cad/motcore_v6_apex_pivot.py`, 31 checks
green). Quantities are **per cube**. The central motor and the electronics are
not included. Parts marked *measure* have provisional dimensions in the macro:
check them on arrival and update the macro.

## Bought

| Qty | Part | Where it goes | Notes |
|---|---|---|---|
| 4 | Bearing 6805 (25×37×7) | output cone's neck | |
| 8 | Bearing MR105ZZ (5×10×4) | output shafts, 2 each | |
| 2 | Bearing 688ZZ (8×16×5) | motor shaft, floor and ceiling | |
| 1 | Ø8 D-shaft, 105 mm | motor shaft | flat 7.5 across — *measure* |
| 4 | Ø5 D-shaft, 35 mm | output shafts | flat 4.5 across — *measure* |
| 4 | Ø4 rod, 53 mm | guide rods | |
| 4 | T8 lead screw, lead 8 (4-start), 62 mm | actuation | stock lengths are 100 mm+: order cut, or cut |
| 1 | T8 anti-backlash kit, CESFONJER (4 sets) | the rectangular-flange nut only | flange holes likely M3 — *measure* |
| 4 | Servo MG90D | actuation | comes with its horns, horn screw (M2.5) and 2 tab screws |
| 4 | T8 lock collar (grub type, ~Ø14×6) | lead screw thrust stop | *measure* |
| 8 | PTFE washer 8×12×1 | lead screw thrust stop | brass + grease also works |
| 8 | Spring stack Ø11/Ø5, ~72 N/mm | series spring, 2 per axis | **part not chosen** (Belleville or die spring) |
| 8 | Dowel ISO 8734 4×24 | four-bar pins A | |
| 8 | Dowel ISO 8734 4×40 | four-bar pins B | |
| 4 | Dowel ISO 8734 3×14 | ear pins | |
| 32 | Dowel Ø2 | cardan cross pins, 8 per axis | lengths still to match to stock |
| ~32 | Shim DIN 988 4×8, 0.1–0.5 mm | four-bar thrust faces | an assortment |
| 8 | M3×10 socket head (DIN 912) | nut flanges | |
| 16 | M3×12 socket head (DIN 912) | frame posts, from outside the decks | |
| 16 | M3×10 countersunk (DIN 7991) | walls to ceiling and floor | |
| 10 | M3 grub screw, ~4 mm | 4 servo couplers + 6 dogs | |
| 24 | Disc magnet N52 10×2 | 4 per face | same pole on the 5 output faces, the other on the input |
| 1 | Rubber sheet, 2 mm | 6 bands: 2 motor cones, 4 output cones | material still open (§10) |

## Printed

| Qty | Part | Material |
|---|---|---|
| 2 | Motor cone (same part, flipped) | PLA |
| 2 | Motor shaft spacer (top 22 mm, bottom 7 mm) | PLA |
| 4 | Wall (servo cradle, guide rod foot and thrust plate built in) | PLA |
| 1 | Ceiling (4 screw-top posts, ribs) | PLA |
| 1 | Floor (ribs, input socket) | PLA |
| 4 | Output cone (shell) | PLA |
| 4 | Carriage | PLA |
| 8 | Link (each carries both arms) | PLA |
| 8 | Frame post (screwed to the decks) | PLA |
| 4 × 4 | Cardan: UJMid, UJRing, UJCross, UJFork | PLA |
| 4 | Spring cage | PLA |
| 4 | Spring carrier | PLA |
| 4 | Servo-to-screw coupler | PLA |
| 5 | Male dog (4 with a D5 bore, 1 with a D8) | PLA or PETG |
| 1 | Female dog, D8 | PLA or PETG — the cube's torque cap |
| 1 | Spider | TPU |

## Not included yet

- Central motor and its male dog adapter.
- AS5600 per output shaft (4), a TCA9548A (fixed I2C address 0x36), controller.
- Calibration coupon (`cad/calibration.py`), to print first.

## Measure on arrival

The D flats (both shafts), the lock collar, the nut's flange holes, the servo
horn (hub Ø7 × 4, arm 5 × 2 as measured by eye), and the rubber's stiffness,
which every torque figure depends on.

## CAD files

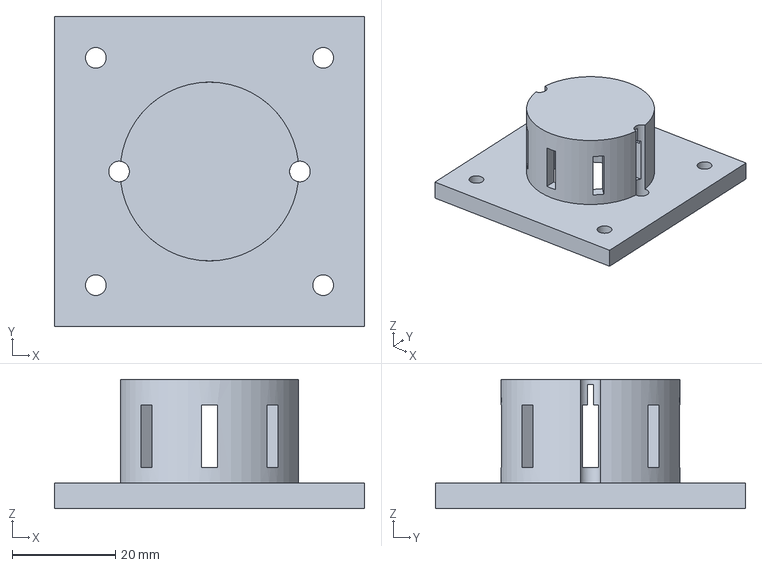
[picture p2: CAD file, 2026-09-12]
cad/MotorMount.FCStd
60.0 x 60.0 x 25.0 mm

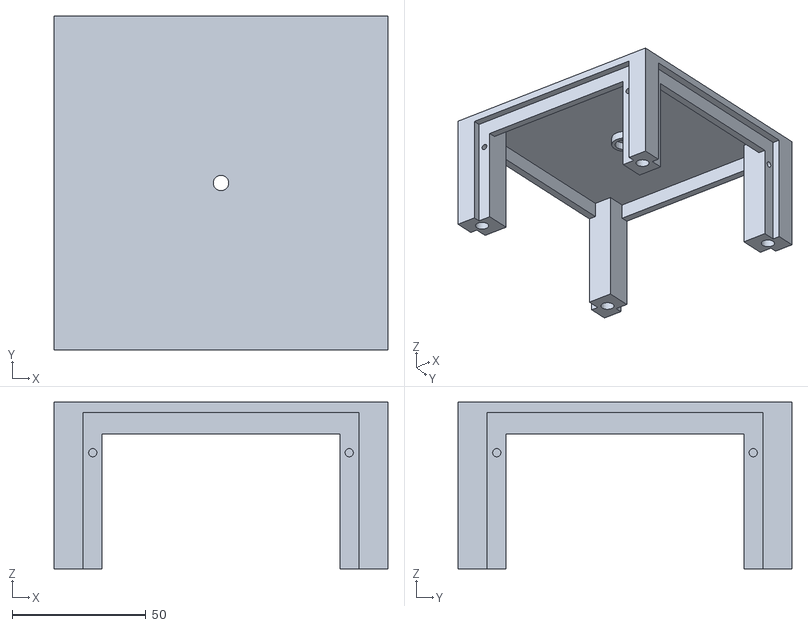
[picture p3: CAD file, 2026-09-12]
cad/stl/motcore_top_plate.stl
124.9 x 124.9 x 62.5

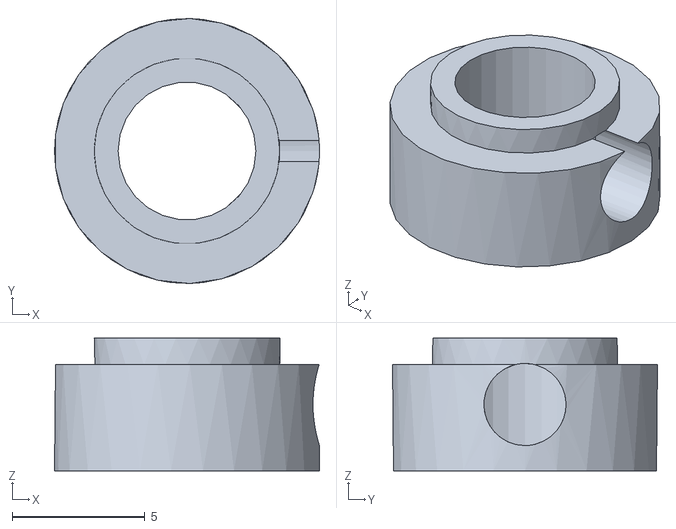
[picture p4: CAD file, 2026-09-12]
cad/stl/motcore_shaft_collar.stl
10.0 x 10.00 x 5.00

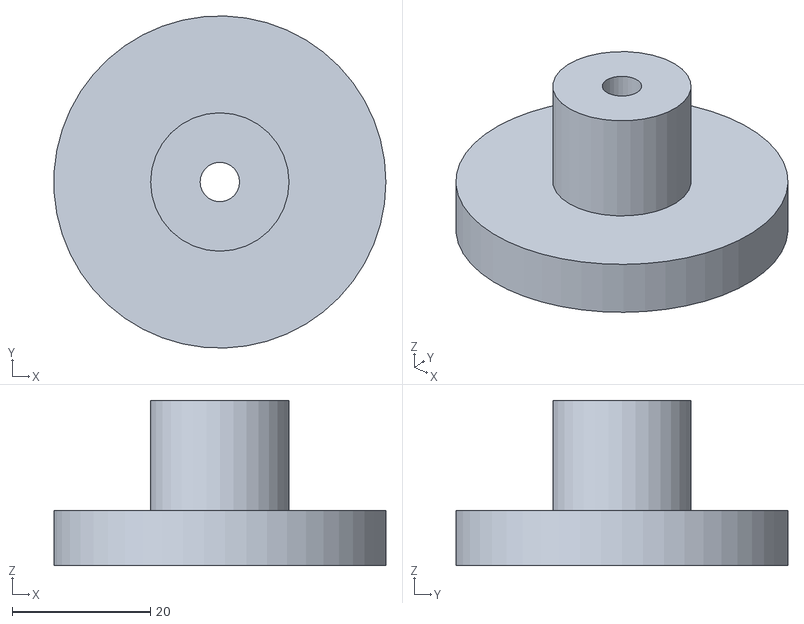
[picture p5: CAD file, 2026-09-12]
cad/stl/motcore_motor_disc_bot.stl
48.0 x 48.0 x 23.9

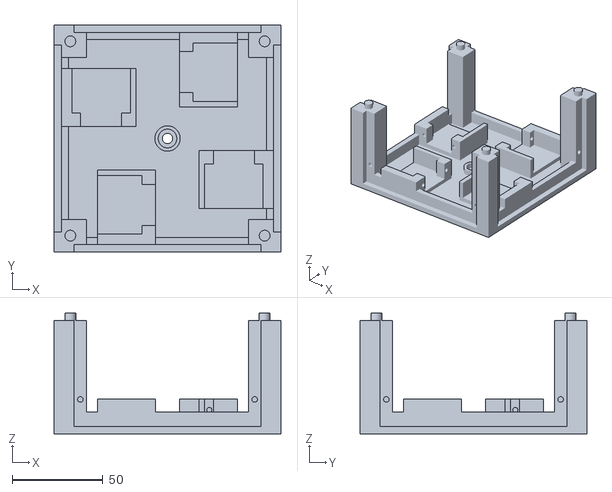
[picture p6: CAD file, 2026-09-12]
cad/stl/motcore_frame_base.stl
124.9 x 124.9 x 66.5

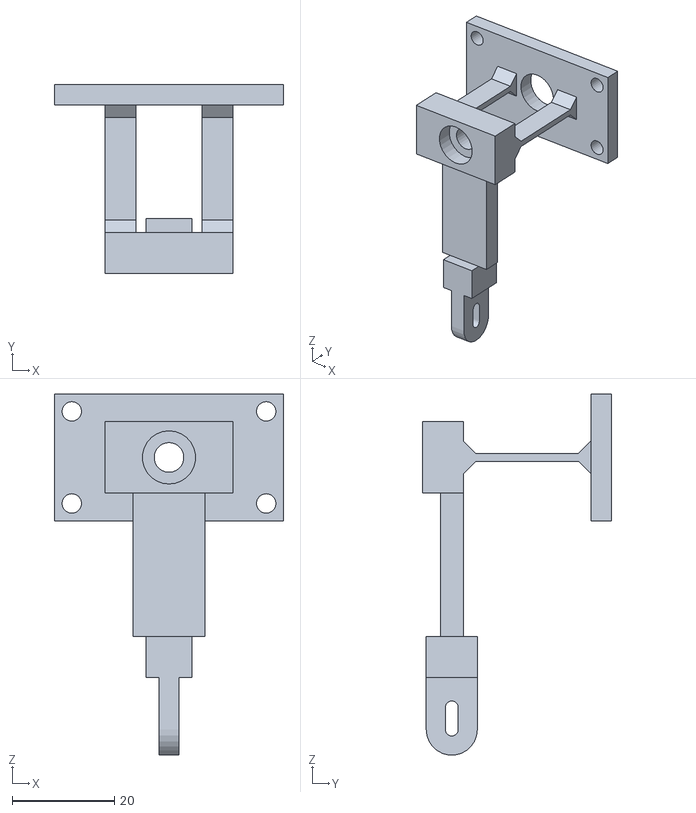
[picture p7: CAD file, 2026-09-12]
cad/stl/motcore_bracket.stl
44.8 x 37.0 x 70.6

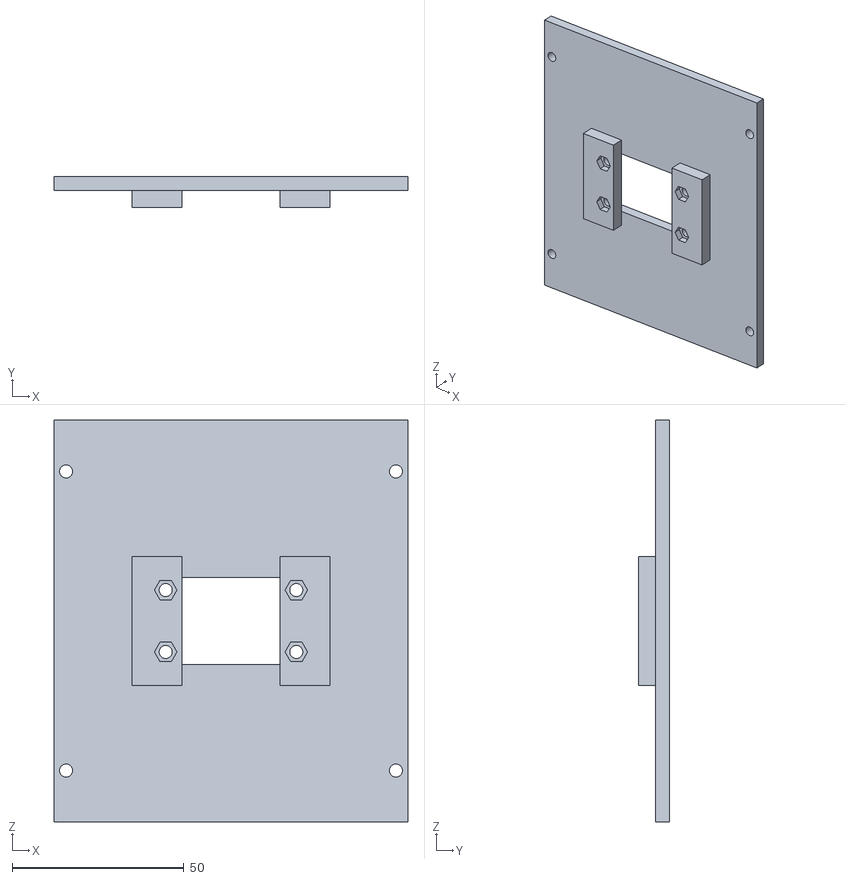
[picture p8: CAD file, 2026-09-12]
cad/stl/motcore_wall.stl
102.9 x 9.00 x 116.9

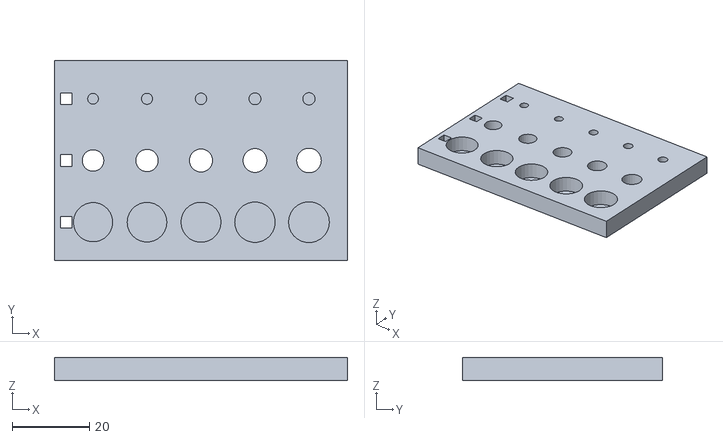
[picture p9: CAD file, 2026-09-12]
cad/stl/motcore_calibration.stl
76.0 x 52.0 x 6.00

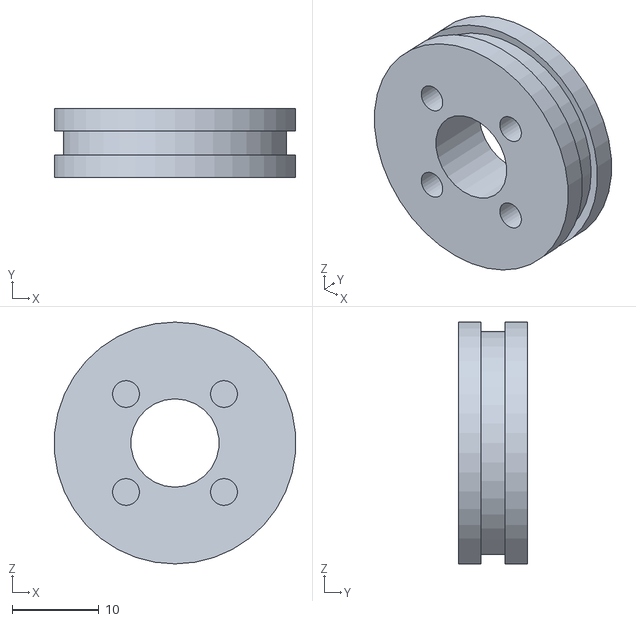
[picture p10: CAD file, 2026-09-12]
cad/stl/motcore_output_wheel.stl
27.8 x 8.00 x 27.9

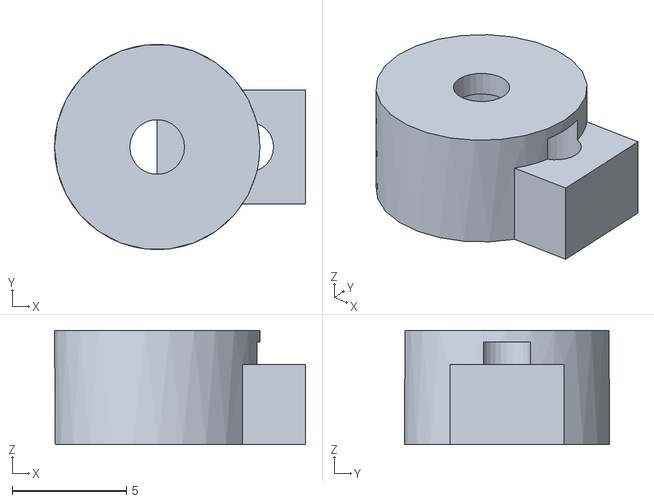
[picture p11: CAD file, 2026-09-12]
cad/stl/motcore_servo_arm.stl
11.0 x 9.00 x 5.00

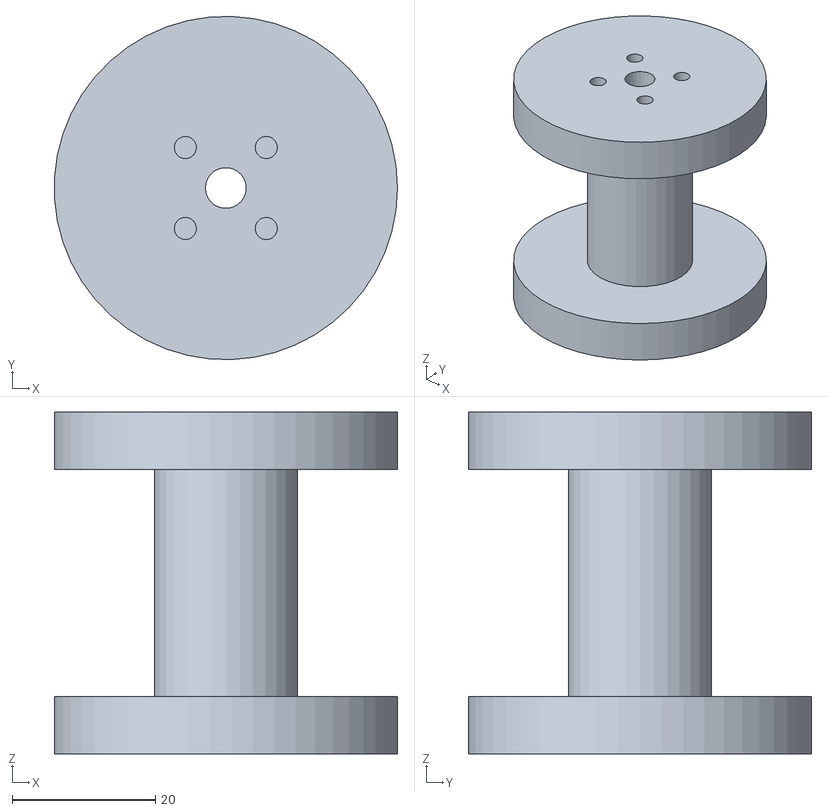
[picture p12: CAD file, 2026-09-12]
cad/stl/motcore_motor_disc.stl
48.0 x 48.0 x 47.8

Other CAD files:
cad/stl/motcore_motor_disc_top.stl

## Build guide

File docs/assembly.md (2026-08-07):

# Assembly Guide — Motcore v0.1

> **Note:** This guide covers the v0.1 proof of concept using LEGO Technic components. A v0.2 guide with 3D-printed parts is in development.

---

## Prerequisites

### Components Required

| Component | Quantity |
|---|---|
| 28BYJ-48 Stepper Motor + ULN2003 driver | 1 |
| SG90 Micro Servo | 4 |
| Arduino Uno R3 | 2 |
| MCUFRIEND TFT Touchscreen 2.4" | 1 |
| Jumper wires | ~30 |
| Breadboard | 1 |
| LEGO Technic axles (5mm, various lengths) | 4+ |
| LEGO Technic beams and connectors | As needed |

### Tools Required

- Small Phillips screwdriver
- USB cable (Type-A to Type-B) × 2
- Computer with Arduino IDE or PlatformIO installed

---

## Step 1 — Mechanical Assembly

### 1.1 Central Motor Mount

1. Mount the 28BYJ-48 stepper motor at the center of the LEGO frame
2. Secure with LEGO beams to ensure the motor shaft is perpendicular to the base
3. Attach a friction hub to the motor shaft

### 1.2 Output Axes

1. Insert four 5mm LEGO Technic axles perpendicular to the central shaft
2. Position them at 90° intervals around the central axis
3. Ensure each axle can slide laterally (5–10mm of travel)

### 1.3 Friction Wheels

1. Attach one SG90 servo per output axis
2. Mount a rubber-coated friction wheel on each servo arm
3. Adjust servo horn position so the wheel makes clean contact with the central shaft when engaged

### 1.4 Frame

1. Build a rigid LEGO frame to hold all components in alignment
2. Verify all axes rotate freely when not engaged
3. Check that friction contact is clean and consistent

---

## Step 2 — Electronics

Refer to [Wiring Diagram](wiring.md) for full pinout details.

1. Connect the ULN2003 driver board to the central stepper motor
2. Connect all four SG90 servos to the master Arduino
3. Attach the MCUFRIEND TFT touchscreen to the master Arduino
4. Connect the two Arduino boards via serial (TX/RX)
5. Power both boards via USB

---

## Step 3 — Firmware Upload

1. Upload `src/controller/` to the **master Arduino** (touchscreen + servo control)
2. Upload `src/driver/` to the **receiver Arduino** (stepper motor control)

See [Firmware Guide](firmware.md) for details.

---

## Step 4 — Testing

1. Power on both Arduino boards
2. The touchscreen should initialize and display the control interface
3. Test each axis independently using the touchscreen buttons
4. Verify the central motor rotates continuously
5. Check that each servo correctly engages and disengages its friction wheel

---

## Troubleshooting

See [Troubleshooting Guide](troubleshooting.md) for common issues.

---

## Next Steps

Once the v0.1 prototype is working, v0.2 will replace the LEGO frame with parametric 3D-printed components. See [3D Models](3d-models.md) for the design in progress.

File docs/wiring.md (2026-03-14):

# Wiring Diagram — Motcore v0.1

---

## System Overview

```
[TFT Touchscreen] ──── [Master Arduino Uno]
                              │
                    ┌─────────┴──────────┐
                    │   Serial TX/RX     │
                    │                    │
              [4x SG90 Servos]   [Receiver Arduino Uno]
                                         │
                                  [ULN2003 Driver]
                                         │
                                 [28BYJ-48 Stepper]
```

---

## Master Arduino — Pinout

### TFT Touchscreen (MCUFRIEND 2.4")

The MCUFRIEND shield plugs directly onto the Master Arduino Uno headers.

| TFT Function | Arduino Pin |
|---|---|
| LCD data bus | D2–D9 |
| LCD RS | A0 |
| LCD WR | A1 |
| LCD CS | A2 |
| LCD RST | A3 |
| Touch XP | A2 |
| Touch YP | A3 |
| Touch XM | D8 |
| Touch YM | D9 |

### Servo Motors

| Servo | Arduino Pin |
|---|---|
| Servo Axis 1 | D3 |
| Servo Axis 2 | D5 |
| Servo Axis 3 | D6 |
| Servo Axis 4 | D9 |

> **Note:** Servo power (5V/GND) should be taken directly from the USB power rail, not from the Arduino 5V pin, to avoid brownouts.

### Serial Communication (to Receiver Arduino)

| Signal | Master Pin | Receiver Pin |
|---|---|---|
| TX → RX | D1 (TX) | D0 (RX) |
| RX ← TX | D0 (RX) | D1 (TX) |
| GND | GND | GND |

> **Important:** Disconnect the serial wires before uploading firmware to either Arduino.

---

## Receiver Arduino — Pinout

### ULN2003 Stepper Driver

| ULN2003 Input | Arduino Pin |
|---|---|
| IN1 | D8 |
| IN2 | D9 |
| IN3 | D10 |
| IN4 | D11 |

### Power

| Connection | Detail |
|---|---|
| Motor power | 5V via USB |
| GND | Shared with Master Arduino |

---

## Power Notes

- Both Arduinos are powered independently via USB (5V)
- Share a common GND between both boards
- Total current draw: ~500mA (within USB spec)
- Servos and stepper should not exceed 5V USB current limits simultaneously

---

## Diagram

> 📷 Wiring diagram image coming soon — see assembly photos in `docs/images/`

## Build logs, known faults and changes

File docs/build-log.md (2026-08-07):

# Motcore — Build Log (Prototype v0.1)

Running journal for a **specific physical build**: purchases, prints, calibrations,
tests and hands-on decisions. Major geometry changes live in git; this is the
day-to-day record that git doesn't capture. **Newest entries at the top.**

> **Scope note.** Entries below Aug 2026 record the **v4 compliant-lever** build
> (metal universal joint, engagement blade, over-centre latch), which is
> superseded — see [design-evolution.md](design-evolution.md). The FDM tolerance
> and bearing calibrations still apply; the v4 mechanical parts do not.

---

## Bill of materials (this prototype)

Status: ✅ have · 🛒 ordered · ⬜ to buy

| Item | Spec | Qty | Status | Notes |
|---|---|-----|---|---|
| Servo | positional ~180° (NOT 360° continuous) | 1+ | ✅ | verify it's the positional one |
| Flange hub Ø5 | flange Ø22, bolt circle Ø16, 4×M3 | 3 (test) / 6 (cube) | ✅ | 4 wheels + 2 disc |
| Bearing | MR105ZZ (Ø5×Ø10×4) | 4 (test) / 10 (cube) | ✅ | one type everywhere |
| Universal joint | Ø11×23, 5 mm bore | 1 / 4 | 🛒 | ordered |
| 3D printer | Creality Hi (without CFS) | 1 | ✅ | |
| Filament dryer | Creality Space Pi | 1 | ✅ | for PETG/Nylon |
| Filament | Hyper PETG 1.75 mm 1 kg, white | 1 | ✅ | functional parts |
| Filament | PLA | 1 | ⬜ | fast fit-check iteration |
| Shaft rod | 6061 aluminium Ø5, 305 mm | 2 | ✅ | soft — OK for test; steel for final |
| Shaft collar | Ø5 bore, Ø10, 5 mm, set screw | 2 | ✅ | comes with grub screw |
| O-ring | 30×25×2.5 (OD×ID×CS), NBR | pack | ✅ | NBR for test; silicone for final |
| Screw kit | M2/M3 socket-head + nuts + washers | 1 | ⬜ | |
| Threadlocker | Loctite 243 (blue) | 1 | ⬜ | on all set screws |
| Allen keys | hex key set | 1 | ⬜ | for socket screws |
| Drive motor | external, spins the central shaft | 1 | ⬜ | drill or DC motor for the test |
| Servo control | servo tester or Arduino + 5–6 V | 1 | ⬜ | firmware in src/ |

---

## Printer calibration

| Printer | Material | Bearing (Ø10) | Shaft (Ø5 slip) | M3 pilot | Date |
|---|---|---|---|---|---|
| Creality Hi | PLA | **10.3** press / 10.4 slip | **5.8** (disc bore 5.6) | **3.1** | 2026-07-07 |

Applied to `motcore_compliant_lever.py` (FDM block): pilots 3.1, disc bore 5.6,
bearing seats press +0.15 (Ø10.3) / slip +0.20 (Ø10.4). Shaft pass-through holes
were already Ø5.8 → left as-is. **Estimated (not directly measured, verify on first
assembly)**: wall-in-groove width 4.8 and peg/socket Ø7.0 (printed male-in-female
fits — forgiving; sand if tight, shim if loose).

Coupon: `cad/calibration.py` → `cad/stl/motcore_calibration.stl`. Once measured,
these offsets get set in `cad/motcore_compliant_lever.py`.

- **Bearing**: a hole modelled at 10.3 gives a good press for the Ø10 MR105 (holds
  when flipped, out with a firm tap); 10.2 was too brutal for brittle PLA. → press
  seat ≈ **10.3**, float ≈ 10.4 (to confirm on v2 coupon).
- **Shaft (v1)**: Ø5 rod only entered the biggest hole (5.5) and even that was zero
  clearance + squeak → **small holes run ~0.5 mm undersize**. Free slip is > 5.5.
- **Pilot (v1)**: M3 didn't self-tap in any (2.3–2.7 → printed ~1.8–2.2, too small).
- → **coupon v2** with shifted ranges (bearing 10.2–10.6, shaft 5.6–6.4, pilot
  2.8–3.2) to nail shaft slip + M3 pilot + bearing float. Reprint & measure.
- Note the disc centring bore (5.0 in the macro) would print ~4.5 → the rod won't
  fit; all shaft holes need bumping up in the FDM tolerance pass.

---

## Print log

| Date | Part | Material | Notes / result |
|---|---|---|---|
| 2026-06-17 | calibration coupon | PLA | printed; measuring |

---

## Test log

| Date | What | Result |
|---|---|---|
| — | — | — |

---

## Backlog — issues found on the first PLA build (2026-07-07)

| # | Issue | Type | Plan |
|---|---|---|---|
| 1 | O-ring loose in the wheel groove (wobbles) | model | ✅ stretch 1%→3% + dovetail groove |
| 2 | O-ring slips (rotates) in its groove — needs grip | model | ✅ **dovetail groove** (revolved trapezoid, bottom 3.25 > opening 2.62) keys the O-ring; verify the revolve + ~16° undercut print in FreeCAD; glue for the current printed wheel |
| 3 | Flexure blade roots need progressive material (fillets) on both sides | model | ✅ tilt blades: 45° gussets both ends + both faces. Engagement-spring (servo lever) root fillets tried then removed — not needed |
| 3b | Head bearing easier to install from the wheel side | model | ✅ head bearing seat now opens toward the wheel (head_y0) instead of the wall side |
| 4 | Bracket supports clogged the holes | print | tree supports / support blockers on holes / reorient; drill out for now |
| 5 | Ø5 aluminium rod won't enter the bearing | hardware | file/sand to fit; consider **mild steel SMOOTH** rod (NOT threaded — a threaded rod rides on its thread tips in a bearing) |
| 6 | Bearing too loose in the frame-base boss | model | the tall boss prints looser than the flat coupon → tighten the plate-boss bearing fit (per-feature) |
| 7 | Wall internal overhangs (foot pocket / bracket seating faces) rough — printed without support | print/model | support there, or chamfer those overhangs < 45° so they print clean |

## Journal

### 2026-07-07
- Printed frame base + top: spotted a **step** where the wall rests — the column
  groove's inner wall didn't line up with the base/top backing rib, and it varied
  per face. Root cause: the groove was positioned asymmetrically for ±sx/±sy
  (0.1 mm on +, ~0.7 mm on −). Fixed: groove inner wall now sits exactly at
  cube_half (= rib plane) on all four faces, clearance moved to the outer side.
  Already-printed frame has the step — usable for the test; reprint later for a
  clean assembly.
- Printed the wall (PLA) — spotted that the M3 **clearance** holes were missed in
  the FDM pass: modelled Ø3.2 → printed ~2.7 → the screw taps the wall instead of
  passing through. Bumped `m3_screw_r` 1.6 → 1.9 (Ø3.8 → ~3.3 free). Already-printed
  wall: drill out to ~3.3 or use as-is. Fix applies to wall/foot/top-plate M3 holes.
- Coupon v2 measured: shaft free slip ≈ 5.8, M3 pilot 3.1, bearing press 10.3.
  Confirmed the printer runs small holes ~0.5 mm undersize.
- Applied the **FDM tolerance pass** to the macro (pilots 3.1, disc bore 5.6,
  bearing seats 10.3/10.4). Peg/socket + wall-groove clearances estimated — to
  verify on the first assembly print. Ready to export the real parts.

### 2026-06-17
- Printed the calibration coupon (PLA) and measured the **bearing row**: 10.3 is a
  good press seat (printer ~0.2–0.3 mm undersize). Shaft/pilot pending (rod + M3
  screws not arrived). Macro fits NOT changed yet — waiting for all three.
- Bought Creality Hi + Space Pi dryer + Hyper PETG 1 kg (white). Coupon printing.
- Decided: PLA for fit-check iteration, PETG for functional test, SLS PA12 for the
  final bracket if needed.
- Bought aluminium Ø5 rod (soft — set-screw/bearing durability lower than steel;
  fine for the first test). O-rings 30×25×2.5 NBR. Shaft collars Ø5 (set-screw).
- Tuned the wheel groove to the real O-ring (ID 25) in the macro.
- Still to source: M2/M3 screw kit, Loctite 243, Allen keys, a motor to spin the
  disc, and a way to command the servo.

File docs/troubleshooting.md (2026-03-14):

# Troubleshooting Guide — Motcore v0.1

---

## Mechanical Issues

### Axis doesn't move when servo engages

**Symptoms:** Servo moves to engaged position but output axis stays still.

**Possible causes:**
- Friction wheel not making contact with the central shaft
- Central motor not spinning
- Friction surface too smooth

**Solutions:**
1. Check that the central stepper motor is running (listen for the motor sound)
2. Adjust the servo angle constants in `controller.ino` to increase contact pressure
3. Add a rubber band or O-ring to the friction wheel for better grip
4. Verify the output axis slides freely and is aligned with the friction wheel

---

### Axis moves erratically or inconsistently

**Symptoms:** Axis moves sometimes but not reliably.

**Possible causes:**
- Insufficient friction contact pressure
- Loose mechanical assembly
- Servo positioning inconsistency

**Solutions:**
1. Increase contact pressure by adjusting servo engaged angle
2. Check all LEGO connections are tight
3. Ensure friction wheel surface is clean (no grease or dust)

---

### All axes move simultaneously

**Symptoms:** Multiple axes move when only one should.

**Possible causes:**
- Friction wheels from different axes are touching

**Solutions:**
1. Increase spacing between output axes
2. Check that only the target servo is engaging

---

## Electronics Issues

### Touchscreen doesn't initialize

**Symptoms:** Black screen or garbled display on startup.

**Possible causes:**
- MCUFRIEND shield not fully seated
- Wrong display driver ID

**Solutions:**
1. Remove and reseat the TFT shield firmly
2. Run the `LCD_ID_readreg` example from MCUFRIEND_kbv library to identify your display ID
3. Verify the correct driver is selected in `controller.ino`

---

### Servos jitter or don't reach position

**Symptoms:** Servos vibrate continuously or don't reach the commanded angle.

**Possible causes:**
- Insufficient power supply
- PWM pin conflict with other peripherals

**Solutions:**
1. Power servos directly from a 5V rail, not from the Arduino 5V pin
2. Check that servo signal wires are connected to PWM-capable pins (marked `~` on Arduino Uno)
3. Add a 100µF capacitor across the servo power rail

---

### Stepper motor doesn't spin

**Symptoms:** No movement from the central 28BYJ-48 motor.

**Possible causes:**
- Loose connection to ULN2003 driver
- Receiver Arduino not receiving serial commands

**Solutions:**
1. Check all four wires between ULN2003 and receiver Arduino
2. Open Serial Monitor on the master Arduino and verify commands are being sent
3. Verify TX/RX serial wires are correctly connected (TX→RX, RX→TX) and GND is shared
4. Disconnect serial wires, upload fresh firmware to receiver Arduino, reconnect

---

### Serial communication not working

**Symptoms:** Stepper doesn't respond to touchscreen input.

**Solutions:**
1. Ensure GND is shared between both Arduinos
2. Verify baud rate is 9600 in both `controller.ino` and `driver.ino`
3. Swap TX/RX wires (common mistake)
4. Remember to **disconnect serial wires before uploading** firmware

---

## Software Issues

### Compilation errors

**Solutions:**
1. Ensure all required libraries are installed (see [Firmware Guide](firmware.md))
2. Select the correct board: **Arduino Uno**
3. Check PlatformIO or Arduino IDE version compatibility

---

## Still stuck?

Open an issue on [GitHub Issues](../../issues) with:
- Description of the problem
- What you've already tried
- Photos of your assembly if it's a mechanical issue
- Serial Monitor output if it's an electronics/software issue

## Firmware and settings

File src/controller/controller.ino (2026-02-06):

// CONTROLLER Arduino with MCUFRIEND touchscreen
// Controls: 1 stepper motor + 4 servos

#include <MCUFRIEND_kbv.h>
#include <TouchScreen.h>
#include <Adafruit_GFX.h>

MCUFRIEND_kbv tft;

// Pin configuration for touchscreen
#define YP A1
#define XM A2
#define YM 7
#define XP 6

// Touchscreen calibration
#define TS_MINX 100
#define TS_MAXX 920
#define TS_MINY 70
#define TS_MAXY 900

// Colors
#define BLACK   0x0000
#define BLUE    0x001F
#define RED     0xF800
#define GREEN   0x07E0
#define CYAN    0x07FF
#define MAGENTA 0xF81F
#define YELLOW  0xFFE0
#define WHITE   0xFFFF
#define ORANGE  0xFD20
#define GRAY    0x8410

TouchScreen ts = TouchScreen(XP, YP, XM, YM, 300);

// Servo positions
#define POS_LEFT   0
#define POS_FREE   90
#define POS_RIGHT  180

// UI Layout constants
#define SCREEN_W 320
#define SCREEN_H 240

// Button dimensions
#define BTN_W 90
#define BTN_H 35
#define BTN_SMALL_W 60

// Row Y positions
#define ROW_STEPPER 45
#define ROW_SERVO1 90
#define ROW_SERVO2 130
#define ROW_SERVO3 170
#define ROW_SERVO4 210

// Track servo positions for display
int servoPos[4] = {POS_FREE, POS_FREE, POS_FREE, POS_FREE};
bool stepperRunning = false;

void setup() {
  Serial.begin(9600);

  uint16_t ID = tft.readID();
  tft.begin(ID);
  tft.setRotation(1);

  tft.fillScreen(BLACK);
  drawInterface();
}

void loop() {
  TSPoint p = ts.getPoint();

  pinMode(YP, OUTPUT);
  pinMode(XM, OUTPUT);

  if (p.z > ts.pressureThreshhold) {
    int x = map(p.x, TS_MINX, TS_MAXX, SCREEN_W, 0);
    int y = map(p.y, TS_MINY, TS_MAXY, 0, SCREEN_H);

    processTouch(x, y);
    delay(200); // Debounce
  }

  delay(50);
}

void drawInterface() {
  // Title
  tft.setTextColor(WHITE);
  tft.setTextSize(2);
  tft.setCursor(50, 10);
  tft.print("Motor & Servo Control");

  // Stepper row
  drawStepperRow();

  // Servo rows
  drawServoRow(0, ROW_SERVO1);
  drawServoRow(1, ROW_SERVO2);
  drawServoRow(2, ROW_SERVO3);
  drawServoRow(3, ROW_SERVO4);
}

void drawStepperRow() {
  // Label
  tft.setTextColor(WHITE);
  tft.setTextSize(1);
  tft.setCursor(5, ROW_STEPPER + 12);
  tft.print("MOTOR");

  // START button
  tft.fillRect(60, ROW_STEPPER, BTN_W, BTN_H, stepperRunning ? GRAY : GREEN);
  tft.setTextColor(WHITE);
  tft.setTextSize(2);
  tft.setCursor(75, ROW_STEPPER + 10);
  tft.print("START");

  // STOP button
  tft.fillRect(170, ROW_STEPPER, BTN_W, BTN_H, stepperRunning ? RED : GRAY);
  tft.setCursor(190, ROW_STEPPER + 10);
  tft.print("STOP");
}

void drawServoRow(int servoNum, int y) {
  // Label
  tft.setTextColor(WHITE);
  tft.setTextSize(1);
  tft.setCursor(5, y + 12);
  tft.print("S");
  tft.print(servoNum + 1);

  int currentPos = servoPos[servoNum];

  // Left button (0)
  tft.fillRect(35, y, BTN_SMALL_W, BTN_H, currentPos == POS_LEFT ? ORANGE : BLUE);
  tft.setTextColor(WHITE);
  tft.setTextSize(1);
  tft.setCursor(55, y + 13);
  tft.print("0");

  // Free button (90)
  tft.fillRect(105, y, BTN_SMALL_W, BTN_H, currentPos == POS_FREE ? ORANGE : CYAN);
  tft.setTextColor(BLACK);
  tft.setCursor(122, y + 13);
  tft.print("90");

  // Right button (180)
  tft.fillRect(175, y, BTN_SMALL_W + 10, BTN_H, currentPos == POS_RIGHT ? ORANGE : BLUE);
  tft.setTextColor(WHITE);
  tft.setCursor(192, y + 13);
  tft.print("180");

  // Current position display
  tft.fillRect(255, y, 60, BTN_H, BLACK);
  tft.setTextColor(YELLOW);
  tft.setCursor(260, y + 13);
  tft.print(currentPos);
  tft.print((char)167);
}

void processTouch(int x, int y) {
  // Check stepper buttons
  if (y >= ROW_STEPPER && y < ROW_STEPPER + BTN_H) {
    // START button
    if (x >= 60 && x < 60 + BTN_W) {
      Serial.write('G');
      stepperRunning = true;
      drawStepperRow();
    }
    // STOP button
    else if (x >= 170 && x < 170 + BTN_W) {
      Serial.write('S');
      stepperRunning = false;
      drawStepperRow();
    }
    return;
  }

  // Check servo buttons
  checkServoTouch(0, ROW_SERVO1, x, y);
  checkServoTouch(1, ROW_SERVO2, x, y);
  checkServoTouch(2, ROW_SERVO3, x, y);
  checkServoTouch(3, ROW_SERVO4, x, y);
}

void checkServoTouch(int servoNum, int rowY, int x, int y) {
  if (y < rowY || y >= rowY + BTN_H) return;

  char cmd = 0;
  int newPos = servoPos[servoNum];

  // Left button (65)
  if (x >= 35 && x < 35 + BTN_SMALL_W) {
    newPos = POS_LEFT;
    cmd = '1' + (servoNum * 3);
  }
  // Free button (90)
  else if (x >= 105 && x < 105 + BTN_SMALL_W) {
    newPos = POS_FREE;
    cmd = '2' + (servoNum * 3);
  }
  // Right button (115)
  else if (x >= 175 && x < 175 + BTN_SMALL_W + 10) {
    newPos = POS_RIGHT;
    cmd = '3' + (servoNum * 3);
  }

  if (cmd != 0) {
    // Servo 4 uses 'a', 'b', 'c' instead of ':', ';', '<'
    if (servoNum == 3) {
      cmd = 'a' + (cmd - '1' - 9);
    }
    Serial.write(cmd);
    servoPos[servoNum] = newPos;
    drawServoRow(servoNum, rowY);
  }
}

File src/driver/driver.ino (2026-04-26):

#include <IRremote.h>
#include <AccelStepper.h>
#include <Servo.h>

#define IR_PIN 2

AccelStepper stepper(AccelStepper::HALF4WIRE, 4, 6, 5, 7);

Servo servo1, servo2, servo3, servo4;

#define SERVO1_PIN 8
#define SERVO2_PIN 9
#define SERVO3_PIN 10
#define SERVO4_PIN 11

#define POS_LEFT 0
#define POS_FREE 90
#define POS_RIGHT 180

bool stepperRunning = false;

void setup() {
  Serial.begin(9600);
  IrReceiver.begin(IR_PIN, ENABLE_LED_FEEDBACK);

  stepper.setMaxSpeed(1000);
  stepper.setAcceleration(200);

  servo1.attach(SERVO1_PIN);
  servo2.attach(SERVO2_PIN);
  servo3.attach(SERVO3_PIN);
  servo4.attach(SERVO4_PIN);

  servo1.write(POS_FREE);
  servo2.write(POS_FREE);
  servo3.write(POS_FREE);
  servo4.write(POS_FREE);

  delay(500);
  Serial.println("Motcore listo");
}

void loop() {
  if (stepperRunning) {
    stepper.runSpeed();
  }

  if (IrReceiver.decode()) {
    processIR(IrReceiver.decodedIRData.command);
    IrReceiver.resume();
  }
}

void processIR(uint8_t cmd) {
  switch (cmd) {
    // Stepper
    case 0x1:  stepperRunning = true;  stepper.setSpeed(500); break; // Vol+
    case 0x2:  stepperRunning = false;                         break; // Func/Stop

    // Servo 1
    case 0x10: servo1.write(POS_LEFT);  break; // 1
    case 0x11: servo1.write(POS_FREE);  break; // 2
    case 0x12: servo1.write(POS_RIGHT); break; // 3

    // Servo 2
    case 0x14: servo2.write(POS_LEFT);  break; // 4
    case 0x15: servo2.write(POS_FREE);  break; // 5
    case 0x16: servo2.write(POS_RIGHT); break; // 6

    // Servo 3
    case 0x18: servo3.write(POS_LEFT);  break; // 7
    case 0x19: servo3.write(POS_FREE);  break; // 8
    case 0x1A: servo3.write(POS_RIGHT); break; // 9

    // Servo 4
    case 0xA: servo4.write(POS_LEFT);  break; // Arriba
    case 0x9: servo4.write(POS_FREE);  break; // Vol-
    case 0x8: servo4.write(POS_RIGHT); break; // Abajo
  }
}

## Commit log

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2025-12-14 Fix touchscreen and improve motor control
    - Fix touchscreen X-axis inversion for correct button detection
    - Swap stepper (pins 4-7) and servo (pins 8-11) pin assignments
    - Change servo left position from 65° to 60°
    - Speed up servo response (15ms → 5ms step delay)
    - Make stepper run continuously with immediate stop
    [controller.ino, driver.ino]
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2026-05-20 feat(cad): refine friction wheel and hub geometry
    - Replace O-ring groove with flat rubber ring (arandela de goma) covering full wheel face
    - Hex head bolt pockets on inward face, oriented with flat side toward center
    - Update hub dimensions from datasheet: flange 3mm, bolt circle 24mm
    - rubber_thick 2mm, rubber_od = wheel_dia (full coverage)
    Assisted by Claude Code (claude.ai/code)
    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
    [motcore_plates.py]
2026-05-20 feat(cad): reduce friction wheel to 40mm, derive rubber_od from wheel_dia
    - wheel_dia reduced from 60mm to 40mm for better clearance around output axes
    - rubber_od now a derived value (= wheel_dia) so both always stay in sync
    - cone_angle auto-updates to ~19deg, closer to 1:1 transmission ratio
    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
    [motcore_plates.py]
2026-05-21 feat(cad): add conical clutch wheel with D-bore and tilt animation
    - Conical clutch wheel (rueda cónica) on output axis:
    - Small face (tip, ⌀16 mm) faces inward toward friction wheels
    - Large face (⌀18 mm) outward toward UJ pivot
    - D-bore built as extruded arc+line profile (fixes omega artefact
    caused by oversized flat box cutting into the cone wall)
    - Radial M3 set-screw (prisionero) tap hole near large face
    - cone_tip_y = −9 mm, arm = 33 mm, tilt ≈ 3.5° to engage rubber ring
    - Output shaft split into two D-shaft segments at UJ pivot (y = −42 mm):
    - Pivoting segment (amber): D-shaped cross-section, tilts with cone wheel
    - Fixed segment (grey): plain cylinder t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
    [motcore_plates.py]
2026-05-21 feat(cad): widen wheel_sep to 40mm, D-shaft output, tilt animation
    - Increase wheel_sep from 30 to 40 mm to allow a larger cone wheel
    and improve adjacent-cone diagonal clearance (~4.2 mm vs ~1.4 mm)
    - Fix cone orientation: small face (tip) inward toward friction wheels,
    large face outward toward UJ pivot — correct contact geometry
    - Fix D-bore construction: arc + line extruded profile replaces the
    cylinder-minus-box approach that produced an omega-shaped artifact
    - Add make_d_shaft_seg() for the pivoting output shaft segment;
    keep the fixed (bearing) segment as a plain cylinder
    - Sync motcore_animate.py parameters with the new geometry
    (r_cw=16, cone_tip_y=-16, arm=26 mm, cone_a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
    [motcore_plates.py]
2026-05-21 feat(cad): position cone tip so large face aligns with friction-wheel outer rim
    Move the cone wheel inward (toward Z axis) so the large face lands at
    y = -wheel_dia/2 = -20 mm (outer rim of the friction wheel), instead
    of the previous -24.6 mm which placed it past the rim with no clear
    geometric reference.
    Derived iteratively: cone_tip_y - cone_h = -wheel_dia/2
    Converges to: cone_tip_y ≈ -9 mm, arm_length ≈ 33 mm,
    cone_angle ≈ 5.2°, cone_h ≈ 11 mm.
    Side effects:
    - Transmission ratio r_fw/r_cw = 9/16 ≈ 0.57 (step-down; more output torque)
    - Adjacent-cone clearance increases to √2×|13-9| ≈ 5.7 mm (better than before)
    - Engagement angle decreases from 6.6°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
    [motcore_plates.py]
2026-05-21 feat(cad): redesign as bevel friction drive — zero differential slip
    Replace the flat friction wheel + small cone (v0.2) with two matching
    bevel cones that share the same apex at the cube centre (0, 0, 50 mm).
    Principle (bevel-gear analogy):
    α_motor + α_clutch = 90° − θ_engage
    For 1:1 ratio → α = (90° − θ_engage) / 2 = 42.5° (at θ_engage = 5°)
    Because both cones share the apex and both rotation axes intersect there,
    the contact-line ratio r_fw/r_cw is constant at every point → pure rolling,
    zero differential slip by construction.
    Key geometry changes:
    - Motor wheel: flat disc → bevel cone α=42.5° on Z shaft, apex at z=50
    - Clutch wheel: small cone → matc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
    [motcore_plates.py]
2026-05-21 fix(cad): restore UJ pivot to wall side (y=-42mm), shift motor cone apex
    The UJ pivot stays at y = -(hs - plate_thick) = -42mm as in the original
    design — the shaft tilts from the wall side, not from the cube centre.
    Geometry adjustment: when the shaft tilts cone_engage_angle (5°) around
    the UJ at y=-42mm, the clutch cone apex (neutral: y=0, z=50) traces an
    arc and arrives at approximately (0, 0, 53.7mm) on the Z axis. The motor
    cone apex is therefore placed at z_apex_motor = z_center + arm * sin(theta)
    = 50 + 42*sin(5°) ≈ 53.7mm so both apices coincide exactly at engagement.
    Output shaft split restored: pivoting D-shaft (apex→UJ, 42mm) + fixed
    cylinder (UJ→wall+stub, 23mm), sam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
    [motcore_plates.py]
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2026-08-28 Add the v5 FreeCAD macro: bidirectional cube, two motor cones
    First solid model of the v5 vertical cone clutch, replacing the 2D
    visualiser as the geometric source of truth.
    Two motor cones sit apex to apex on the central shaft, with one output
    cone per axis in the waist between them. Both cones turn the same way,
    but their flanks face opposite sides of the output axis, so driving the
    carriage down or up reverses the output shaft: one motor, one axis, both
    directions, without ever reversing the motor. This is v3/v4's "one disc,
    two usable faces" in cone form. Free is therefore the MIDDLE of the
    travel, and the four-stop ladder runs symmetrically both ways.
    The apex separation is derived, n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
    [motcore_v5_vertical_clutch.py]
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2026-09-12 Flesh out the v5 macro: rod end plates, follower, asymmetric rails
    Adds end plates that actually hold the guide rods, a series-elastic
    follower riding on the far rail, and an AXES_SHOWN parameter to render
    fewer than four axes at once. The two rails are no longer symmetric: the
    near one is a plain carriage guide, the far one also guides the follower.
    Superseded by v6, kept because this macro stays the reference for cone
    solids, FDM hole compensation, the gear helpers and the self-check
    scaffolding.
    [motcore_v5_vertical_clutch.py]
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2026-09-14 Add the v6 macro: apex-pivot solids, four-bar solve, self-checks
    Builds the full v6 axis from the design doc: three cones sharing one apex
    with the plastic ones pulled back by t/sin(half-angle), a continuous
    rubber layer, the four-bar virtual pivot solved numerically, a
    permanently meshed pinion/idlers/corona stage, and the servo crank with
    its telescopic spring link. Cone solids, FDM hole compensation, the gear
    helpers and the check scaffolding come from the v5 macro.
    Answers open question 10.3, and the answer is worse than the estimate.
    The four-bar's apex drift is 0.22 mm at full preload, 0.97% of slip -
    an order better than v5's 7.4% - but the drift is almost entirely along
    +Y, so it al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
    [motcore_v6_apex_pivot.py]
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2026-09-14 Make the carriage printable, and model the fasteners
    The carriage is built entirely from prisms swept along X, so it is a 2.5D
    extrusion and prints without a single overhang lying on its side - except
    for the bearing seats, whose axis is Y and which are the one press fit in
    the part. Splitting it on x = 0 resolves that: each seat becomes a
    half-round pocket opening in the print direction, every pin and bolt hole
    becomes vertical, and the two halves come out identical, so it is one
    printed part made twice. A check confirms it, by rotating one half 180
    deg about the shaft axis and taking the symmetric difference with the
    other - a property one asymmetric feature would quietly destroy.
    The hal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
    [motcore_v6_apex_pivot.py]
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2026-09-15 Bring the docs up to the repacked geometry
    The moment arm is the one that mattered: the macro measures the perpendicular
    distance from the apex to the actuation link's line of action, and it is 42.3 mm,
    not R_push. Both documents said R_push, in the torque formula and in the force
    lever, and both numbers were wrong by 10-20% in different directions. The macro
    printed R_push/s_bar for the normal force too; that is now lever/s_bar.
    Also: the four-bar table and its measured drift, the horn and the push point off
    the centre line, the servo on the deck with its case inboard, the turned-over
    alternate axes, the 119 mm cube, and the spring split as a ratio-at-a-radius.
    Open questions 3 (four-bar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
    [motcore_v6_apex_pivot.py]
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2026-09-16 Simplify the carriage: prismatic block + true L-shaped arms
    The housing was a cylinder end to end, tangent-jointed to two diagonal arms
    and an L-shaped horn. Only the inboard portion of that cylinder actually needs
    to be round: past the cone's own mouth (block_y0 = out_base_y + run_clr) there
    is no cavity left to clear, so the housing squares off into a prismatic block
    there, and the arms and the horn now root on its flat faces directly instead
    of on a web tangent to a curve.
    Each arm becomes a real L — a vertical leg straight up from the block, at a Y
    well clear of the cone's rim, then a short horizontal leg in at the pivot's
    own height — replacing the single diagonal bar. The diagonal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
    [motcore_v6_apex_pivot.py]
2026-09-16 Carriage arms: two elongated uprights instead of four short ones — an H
    Each side used to carry two separate short vertical ribs (one per pivot
    height) plus two separate short webs, with only the block's own height
    between them. They collapse into one prism per side, spanning the full range
    from the lower pivot's height to the upper one's, at the same Y the L version
    already proved clear of the cone's rim — with the short horizontal jog at
    each end unchanged, still reaching its own pivot.
    With the block as the crossbar and these two uprights either side of the
    axis, the carriage reads as an H at a glance. The L was already true to how
    force gets to each pivot; this is true to how the fo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
    [motcore_v6_apex_pivot.py]
2026-09-16 Slide the link knuckle further off the B pivot — 17.5 to 15.0
    At 17.5 (4 mm off B) the knuckle's own 5 mm radius reached PAST the pivot,
    visually fusing into the arm's own end boss there — harmless (same part) but
    it reads as an overlap in any view. 15.0 clears B by 6.5 mm, genuinely apart,
    and still keeps 2.2 mm off the frame post, the tighter constraint from here
    inboard (re-measured fresh on this branch: safe window is d in [14, 20]).
    21 of 21 checks still pass.
    [motcore_v6_apex_pivot.py]
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2026-09-16 Output shaft: one MR105ZZ in the wall, fixed both ways, replacing two bushings
    The two polymer bushings assumed the output shaft needed to float axially,
    carried over from the double-cardan branch where the drive's own length
    changed under tilt. With a single Oldham that isn't true: the coupling's own
    local clearance (oldham_float) absorbs the disc's nod right at the disc, and
    nothing past it needs to move.
    Reuses the project's one standard bearing, make_carriage_bearing, instead of
    a bespoke part. Its 4 mm width already matches the wall's own 4 mm thickness,
    so the boss only needs to stand 1.5 mm proud (the shoulder) instead of the
    14 mm the two bushings needed — smaller AND more rigid,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
    [motcore_v6_apex_pivot.py]
2026-09-16 Frame pivots: move from the decks to the wall
    At the user's request: every support for an axis should live on the one part
    that comes off the machine, so pulling the wall frees the whole mechanism
    instead of needing the decks unscrewed too.
    The cube has grown a lot since a wall mount was last tried here (the docs
    once put that cantilever at 35 mm, when the corona's clearance drove the
    cube) — today wall_face_y - fb_A[0] is under 4 mm, short enough that the
    reach needs no engineering to survive.
    What it does need is routing around what already lives in that stretch of
    wall. Fixed by measurement, not by eye, each time a check caught the real
    shape:
    - the link's own arms sweep further from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
    [motcore_v6_apex_pivot.py]
2026-09-16 Servo bracket: move to the wall too, jogging clear of the frame post
    Same request as the frame pivots: every support on this axis lives on the
    wall now, deck_screws() is empty. The far tab is the second-shortest wall
    reach available (~16 mm short, against the frame pivots' ~4) — checked
    before committing to it: crank_hub_y can only move about 1 mm toward the
    wall before it fouls the lower link (measured across the full stroke, not
    assumed from the ~24 mm figure the file already carried), so shifting the
    crank doesn't meaningfully shorten this reach.
    The bottom frame post's own foot already owns the wall directly out from the
    servo — fb_A[1] and crank_hub[1] are only 3.95 mm apart in Z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
    [motcore_v6_apex_pivot.py]
2026-09-16 Turn the servo 180 deg on its own shaft, so its case reaches the wall
    The user's catch: the bracket was bolted to the wall, but the SERVO ITSELF
    hadn't moved — a long arm reaching to a foot, not "on the wall". The user
    placed the real fix: the case used to run inboard from the crank, "under the
    corona" — a corona that no longer exists in this design. Flipping the case
    180 deg about its own shaft (servo_box now derives y0 from 0.25*by instead of
    0.75*by) puts the case's own bulk toward the wall instead of a bracket
    reaching to it.
    crank_hub_y came down from 24 to 14. It looks like a retreat but isn't: the
    constraint reversed sides. It used to be capped going UP by the lower link
    sweeping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
    [motcore_v6_apex_pivot.py]
2026-09-17 Replace the Oldham with a folded double cardan inside the cone
    The cone becomes the outer yoke: hollow, with a neck carrying one 6805 on
    the outside (held by a ring-shaped carriage) and a ring cross on X pins on
    the inside. An intermediate tube runs back to a solid cross on the output
    shaft's fork at y 26, which reaches in through the ring. The carriage shaft
    and its two MR105ZZ are gone; the output shaft now runs in two MR105ZZ
    (inner boss + wall seat).
    Four-bar moved to ray 45 deg, frame pivot r 55 (link 14.5, slip 0.61%),
    knuckle on B, so the frame post no longer sets the cube. Cube 120.8 -> 103.2.
    New checks: cardan running clearance swept over the stroke (0.54 mm, ring
    bore vs output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
    [motcore_v6_apex_pivot.py]
2026-09-17 Rebuild the actuation under the ceiling: torsion spring, 2:1 lever, no turned-over axes
    The servo lies under the ceiling in its axis' own corner, shaft along +X.
    Chain, one Y-Z plane per part stacked in X: torsion spring on the spline ->
    horn (r 8.53, derived) -> link1 -> lever 8/4 on a post from the ceiling ->
    link2 -> an ear bridged off the carriage's +X arm. The telescopic spring
    link, crank, horn-on-carriage and push trunnion are gone.
    Sweep split: 20 deg of servo to contact, 60 more winding the spring
    (2.4 N.mm/deg, 80% of MG90 stall). 34 N on the ear, ~1 Nm output ceiling.
    All four axes are now identical rotated copies; alternate axes are no
    longer turned over, since each servo has a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
    [motcore_v6_apex_pivot.py]
2026-09-17 Stack the actuation chain inboard under the servo, sweep it, 45 deg arms
    The chain past the horn now stacks back INBOARD under the servo's face
    (the case ends before the chain's Y): link1 and the lever's post, lever,
    link2, ear. The ear lands beside the carriage's own arm, so its bridge
    is a ~6 mm stub instead of 22, and the carriage is 45 mm wide in X, not 60.
    New check: the chain swept as distances over 9 tilts against the servo,
    its bracket, the spring, the lever post, the frame posts and the wall
    (pinned neighbours excluded). It found the lever 0.32 mm off the servo
    case (the gap is horn_r - 8.2); fixed with the lever at 8/3.8 (2.1:1)
    and 2 mm lower (z 35), which lengthens link1 to 7.6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
    [motcore_v6_apex_pivot.py]
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2026-09-17 Flush the carriage uprights with the housing ring, and the link knuckles with their arms
    The carriage's uprights are centred on the housing ring and as wide as it
    (y 33..42), instead of a 7 mm bar at y 36 standing off both faces. The
    link knuckle takes the arms' own end radius (4.0) and runs across both arms
    to their outer faces, so it reads as one cylinder; being smaller, it also
    opens the swept link-to-motor-cone clearance from 1.40 to 1.90 mm.
    22/22, cube 106.4.
    [motcore_v6_apex_pivot.py]
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2026-09-17 Make the cardan's solid cross a prism: one through pin, two deep stubs
    The 5 mm cube could not take two pins crossing at its centre: each would
    only sit ~1.5 mm in it, less than the 1.75 mm a tube pin can slide before
    the cone stops it, and the fork's pins carry ~125 N a side at 1 Nm.
    Now a 4.6 x 4 x 10 mm prism, narrow in X and long in Z. One pin goes right
    through its narrow X into both fork arms; the two pins to the intermediate
    go into blind holes in its long ends, 3.5 mm deep, stopping clear of the
    through pin, so they cannot work loose.
    New check: the prism's far corner against the tube's bore at any phase of
    the turn (0.89 mm) - the model draws one phase only. The cardan sweep now
    i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
    [motcore_v6_apex_pivot.py]
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2026-09-18 Locate the carriage in X: shimmed thrust faces at every four-bar joint
    The carriage had +-2 mm of X play (1.5 per side at B, 0.5 at A), which moves
    the apex off the motor's and slips like the four-bar's own drift (d / L):
    ~8.7%. Thrust bosses on the carriage arms, lug derived from the link, both
    printed shim_gap short and filled with 4x8 shims. Foot slot now clears the
    link in X instead of gripping it at zero clearance. Two new checks.
    [motcore_v6_apex_pivot.py]
2026-09-18 Pin retention: press in one part, run in the other, E-clips on the chain
    Four-bar pins press into the middle part (lug at A, link at B) and need no
    clip: the straddling part cannot come off. Actuation pins press into one
    plate; the running plate is held by a DIN 6799 RS 2.3 clip 0.1 mm off its
    face, side chosen by a sweep. Fixes found on the way: the frame pins at A
    could not be inserted (channel through the foot), Ø3 running holes were
    modelled too small for this printer, and the horn and link1 ran 0.21 mm
    under the ceiling (decks added to the chain sweep, 1 mm ceiling relief).
    [motcore_v6_apex_pivot.py]
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2026-09-20 Make the macro run in half the time without dropping a check
    119 s to 48 s. Shapes are built once and handed out (the carriage was rebuilt
    at every pose of every sweep, the frame brackets four times a run), poses are
    cached (each one costs a four-bar bisection), the distance sweeps skip any
    pair whose bounding boxes are already further apart than the best distance
    found so far (a true lower bound, so the answers do not change), the X-play
    test crops both solids to the joint before nudging them, and the four-axis
    check compares parts pairwise instead of fusing forty of them into one solid.
    [motcore_v6_apex_pivot.py]
2026-09-20 Stand the servo in the corner, shaft outward, ear bridging over it
    The user's layout. Standing (length into the cube, 12.2 tall) and turned so
    the shaft points -X, the servo's base lands beside the four-bar's pin and the
    chain gets the 7.8 mm corner behind the shaft to itself, instead of sharing
    8.8 mm with the four-bar's links. The carriage's ear bridges over the case,
    which standing is low enough to clear. No clips left in the chain: at 0.4 mm
    plate to plate nothing can slide off a pin, and a clip would not fit anyway.
    Force at the ear unchanged (34 N, 0.97 Nm), transmission better at 52 deg.
    The carriage pays for it: 66 mm wide in X against 43.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
    [motcore_v6_apex_pivot.py]
2026-09-20 Drive the carriage with a lead screw instead of a linkage
    The user's idea. The servo stands upright on the floor in its corner, shaft
    up, turning a T8 screw whose nut pushes the ear on the carriage's arm. Every
    linkage before this fought the same constraint - all its pins are parallel to
    X, so crank, link and ear had to share a slice of a cube that is full - and a
    screw sidesteps it entirely.
    57 N at the ear against 34, so the torque ceiling goes to 1.6 Nm, and the
    series spring becomes a catalogue compression spring. The tight part is the
    travel: closing the 2 degree free gap eats 62 of the servo's 80 degrees,
    leaving 0.40 mm of spring squeeze, which wants a ~140 N/mm spring.
    Servo dimens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
    [motcore_v6_apex_pivot.py]
2026-09-20 Guide rod for the nut, and the servo's bracket onto the wall
    The nut needs something to stop it turning with the screw: a 4 mm rod through
    a bore in a stub on the nut, footed on the wall above the servo and on the
    screw's own top post. It rides on the FAR side of the screw from the
    carriage, which is the only place it fits: nearer than 7 mm it fouls the nut,
    further than 7.2 it crosses the carriage's ring on the way up.
    The servo's bracket moves from the floor to the WALL (user), where its back
    already sits 3 mm away: a plate with a pad under each mounting tab.
    Servo shaft corrected again: 6.25 mm from the case's side (user), so 4.95 off
    its centreline, not 1.5. The case moves 3.5 mm along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
    [motcore_v6_apex_pivot.py]
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2026-09-20 Servo case is 28.2 tall; the datasheet's 32.2 includes the spline
    The user's correction. The case and the 4 mm splined shaft are now separate
    numbers, the mounting tabs are measured 18 mm up from the base (which is what
    the bracket holds) rather than back from the shaft end, and the screw starts
    clear of the spline and its coupler. The servo moved 1 mm further from the
    motor to keep its tab plate off the carriage arm's jog: that corner has
    0.27 mm of slack between the neighbour's wall and the arm, and every
    dimension correction has been spending it.
    [motcore_v6_apex_pivot.py]
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2026-09-20 Check that fixed parts clear each other, not just that they do not overlap
    Three faults in one session were 'almost touching' or 'half held', and every
    one was found by looking at the model rather than by a check: a servo tab
    0.07 mm off the carriage arm, a guide rod in half a bore, a bracket rib
    grazing a case. Overlap checks pass all of them. This measures the real gap
    between every pair of fixed parts, with the designed contacts - welded,
    pressed, seated, screwed - listed explicitly. Worst gap today is 1.00 mm.
    [motcore_v6_apex_pivot.py]
2026-09-20 Draw welded brackets only inside their host, not twice
    The user spotted the screw's top support appearing both in the wall and as a
    loose part. It is both, by construction: the brackets are fused into the wall
    so it prints as one piece, and kept as named parts so the checks can still
    see them individually. Only the drawing needed fixing.
    [motcore_v6_apex_pivot.py]
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2026-09-20 Join the carrier to the ear with a pin in a slot, and get the carriage flat again
    Two things the user spotted in the model. The carrier stopped 6 mm short of
    the ear with its hole cut in mid air: its arm now reaches the carriage's own
    arm (at the ear's height the ring's silhouette has ended, so the last
    millimetres are free), a Ø3 pin joins them, pressed into the ear and running
    in the carrier, and the carrier's hole is a SLOT because the ear swings on an
    arc while the nut goes straight - 0.64 mm over the stroke.
    And the ear's boss stood 2 mm proud of the ring's outer face, which is the
    face the carriage prints on. Moving the ear from y 40 to 38 puts the whole
    part back on one plane: 719 m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
    [motcore_v6_apex_pivot.py]
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

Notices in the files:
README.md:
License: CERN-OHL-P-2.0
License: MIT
